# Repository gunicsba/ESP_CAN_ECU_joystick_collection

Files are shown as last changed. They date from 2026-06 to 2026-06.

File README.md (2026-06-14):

# Forwarder CAN Controller

ESP32-based CAN bus control system for a forwarder (logging machine) hydraulic valve block.
It replaces a failed factory controller with a robust, open-source solution using J1939-like addressing over a 250 kbps CAN bus.

## Overview

This project is split into three ECUs on one shared CAN network:

| ECU | Address | Role |
|-----|---|---|
| Motor Driver | `0x20` | Controls 8 solenoids via a PCA9685 PWM driver |
| Joystick 1 | `0x21` | Reads 3 potentiometers + 2 buttons and publishes data on CAN |
| Joystick 2 | `0x22` | Reads 3 potentiometers + 2 buttons and publishes data on CAN |

## Demo Video

See the joystick and CAN controller project in action:

- https://youtube.com/shorts/DkzHTf-jfCc?is=lRpg4t4KHVOdaWYg

## Why this project matters

This repository documents an open-source embedded controller for forestry machinery, specifically a forwarder crane control system with CAN bus joysticks, motor drivers, and hydraulic solenoid outputs. It is useful for anyone building or repairing custom CAN-based mobile machinery controls using ESP32 and PlatformIO.

## Hardware

### T-CAN485 (LilyGO) - Joystick ECU

- **MCU**: ESP32 (regular, not S3) with built-in TJA1050 CAN transceiver
- **CAN pins**: TX = GPIO27, RX = GPIO26
- **Transceiver control**: GPIO16 (`ME2107_EN`, must be HIGH), GPIO23 (`SPEED_MODE`, LOW = high-speed)
- **Joystick inputs**: 3 potentiometers on GPIO32, GPIO33, GPIO34 + 2 buttons on GPIO12 and GPIO5
- **Status LED**: WS2812B on GPIO18

### Motor Driver ECU

- **MCU**: LilyGO T-CAN board (ESP32 with built-in CAN transceiver)
- **Motor driver PCB**: PCA9685 I2C PWM controller with 8 MOSFET outputs

## Joystick Hardware

### Joystick used in this project

This project uses the following joystick model:

- AliExpress listing: https://www.aliexpress.com/item/1005001844154962.html

### 3rd axis wiring

For the 3rd axis on the joystick:

- **2x yellow wires**: button
- **White + red**: GND + power
- **Black**: signal

> The black wire is the signal wire, which is a bit unintuitive, but that is how this joystick is wired.

## 3D Printed Parts

### 3D printable joystick case

A 3D-printable case for the joystick is also included in this repository.

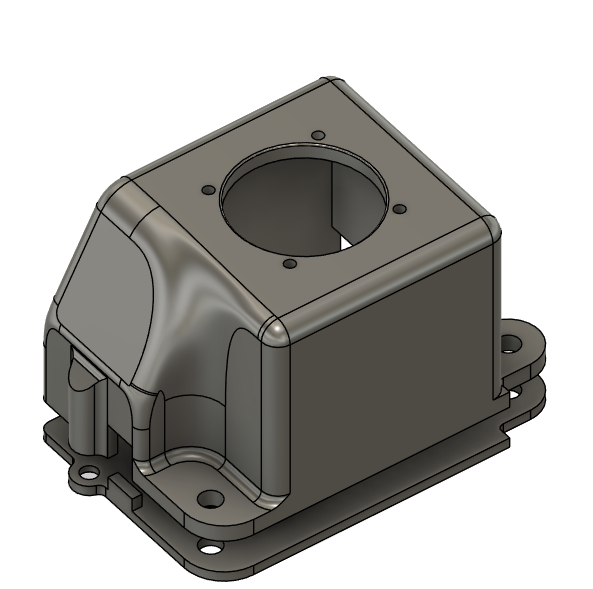
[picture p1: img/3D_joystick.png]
3D printable joystick case


## CAN Protocol

- **Bitrate**: 250 kbps
- **Frame format**: 29-bit extended IDs, J1939-style layout

### ID Structure

```
Bits 28-26: Priority (3 bits)
Bit 25:     Extended Data Page (0)
Bit 24:     Data Page (0)
Bits 23-16: PDU Format (PF)
Bits 15-8:  PDU Specific (PS) = Destination Address when PF < 240
Bits 7-0:   Source Address (SA)
```

### Joystick ECU Transmitted Messages (25Hz)

All messages are broadcast (PS = `0xFF`) with priority 6.

| PF | Name | Rate | Data Bytes | Description |
|----|---|---|---|---|
| `0x10` | `PF_JOYSTICK_POT1` | 25Hz | 2 | Potentiometer 1 value, little-endian (10-bit, 0-1023) |
| `0x11` | `PF_JOYSTICK_POT2` | 25Hz | 2 | Potentiometer 2 value, little-endian (10-bit, 0-1023) |
| `0x12` | `PF_JOYSTICK_POT3` | 25Hz | 2 | Potentiometer 3 value, little-endian (10-bit, 0-1023) |
| `0x13` | `PF_JOYSTICK_BUTTONS` | 25Hz | 1 | Button bitmask: bit0 = BTN1, bit1 = BTN2 |
| `0x30` | `PF_HEARTBEAT` | 1Hz | 8 | Status/heartbeat |

#### Potentiometer Data Format

```
Byte 0: value & 0xFF        (low byte)
Byte 1: (value >> 8) & 0xFF (high byte)
```

Example: value 512 → `data[0] = 0x00, data[1] = 0x02`

#### Button Data Format

```
Byte 0: bitmask
  bit 0: Button 1 (0x01) - active when pressed
  bit 1: Button 2 (0x02) - active when pressed
  bits 2-7: reserved (0)
```

Example: both buttons pressed → `data[0] = 0x03`

#### Heartbeat Data Format (PF `0x30`)

```
Byte 0: online flag (0x01 = address claimed, 0x00 = not claimed)
Byte 1: uptime seconds (low byte)
Byte 2: uptime seconds (high byte)
Byte 3: ECU joystick ID (1 or 2)
Byte 4: RX message count (low byte)
Byte 5: TX message count (low byte)
Byte 6-7: reserved (0)
```

### Network Management Messages

| PF | PS | Direction | Description | Payload |
|----|----|---|---|---|
| `0xEE` | `0xFF` | Broadcast | Address Claimed | 8-byte NAME (unique ECU identifier) |
| `0xEA` | `0xFF` | Broadcast | Request Address Claimed | - |

### Messages Received by Joystick ECU

| PF | PS | Source | Description | Payload |
|----|----|---|---|---|
| `0x20` | DA or `0xFF` | Any | Set LED Color | `R, G, B` (3 bytes) |
| `0x22` | DA or `0xFF` | Any | Identify (blink LED) | `duration` (1 byte, seconds) |

### Motor Driver Messages

| PF | PS | Direction | Description | Payload |
|----|----|---|---|---|
| `0x21` | DA | Any -> Motor | Solenoid Command | `duty0..duty7` (8 bytes, 0-255 each) |

## Pinout (T-CAN485 Joystick)

| Signal | GPIO | Notes |
|---|---|---|
| CAN TX | 27 | Built-in TJA1050 transceiver |
| CAN RX | 26 | Built-in TJA1050 transceiver |
| ME2107_EN | 16 | Transceiver power enable (HIGH) |
| SPEED_MODE | 23 | TJA1050 speed mode (LOW = high-speed) |
| WS2812 | 4 | Status LED |
| Pot 1 | 32 | Joystick X (analog input) |
| Pot 2 | 33 | Joystick Y (analog input) |
| Pot 3 | 34 | Joystick Z (analog input) |
| Button 1 | 12 | Active low, internal pullup |
| Button 2 | 5 | Active low, internal pullup |

## Joystick ECU LED Status Indicators

The WS2812B RGB LED on the joystick ECU provides visual status feedback:

| LED Pattern | Meaning | Condition |
|---|---|---|
| **Solid GREEN** (full brightness) | Normal operation | CAN bus online, motor ECU responding |
| **Solid RED** | Motor ECU offline | No CAN messages from motor ECU (`0x20`) for 1+ second |
| **Blinking RED** (500 ms) | CAN bus broken | No CAN messages from other devices for 2+ seconds |
| **Flashing WHITE** | Identify mode | `PF_IDENTIFY` message received, lasts 3 seconds |
| **Custom RGB** | Remote command | `PF_LED_COLOR` message overrides default color |

### Detection Logic

**Priority order** (highest to lowest):
1. Identify (white flash, 3 seconds)
2. CAN bus broken (blinking red) — message timeout + TWAI hardware check
3. Motor ECU offline (solid red) — message timeout
4. Custom LED color from `PF_LED_COLOR` command
5. Default green (`0, 255, 0`)

**CAN Bus Broken** is detected when any of:
- No CAN messages from **other devices** for 2+ seconds (own messages filtered to avoid loopback false negatives in `TWAI_MODE_NO_ACK`)
- `TWAI_STATE_STOPPED` — TWAI driver stopped
- `TWAI_STATE_BUS_OFF` — Bus-off due to errors
- `tx_error_counter >= 127` — High transmit error count

> **Note:** In `TWAI_MODE_NO_ACK`, the ESP32 may receive its own transmitted messages (loopback). The detection filters these out by checking `sa != g_can->getAddress()` so that a disconnected CAN node does not falsely appear healthy.

**Motor ECU Offline** is detected when:
- No CAN messages are received from source address `0x20` for more than 1 second
- It only triggers if the CAN bus is **not** broken (bus check has priority)

## Building & Flashing

Install [PlatformIO](https://platformio.org/) (VS Code extension or CLI).

```bash
# Build motor driver
pio run -e motor_driver

# Build joystick 1
pio run -e joystick1

# Build joystick 2
pio run -e joystick2

# Flash motor driver
pio run -e motor_driver --target upload

# Flash joystick 1
pio run -e joystick1 --target upload
```

### OTA Updates

OTA builds include a Wi-Fi access point and web upload interface.

```bash
# Build & upload joystick 1 with OTA support
pio run -e joystick1_ota --target upload
```

After booting:
1. Connect to the AP named `forwarder-joy1-21` (or `forwarder-joy2-22`)
2. Password: `12345678`
3. Open http://192.168.4.1
4. Upload a `.bin` firmware file

To produce a `.bin` for OTA:

```bash
pio run -e joystick1
# The .bin will be in .pio/build/joystick1/firmware.bin
```

## Screenshots

### Modules overview

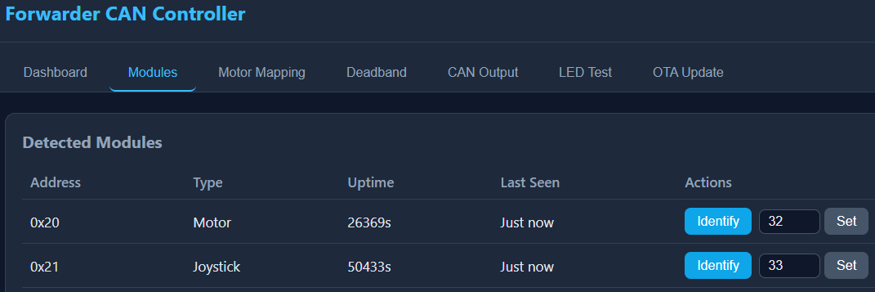
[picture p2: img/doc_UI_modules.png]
Modules overview


### Outputs view

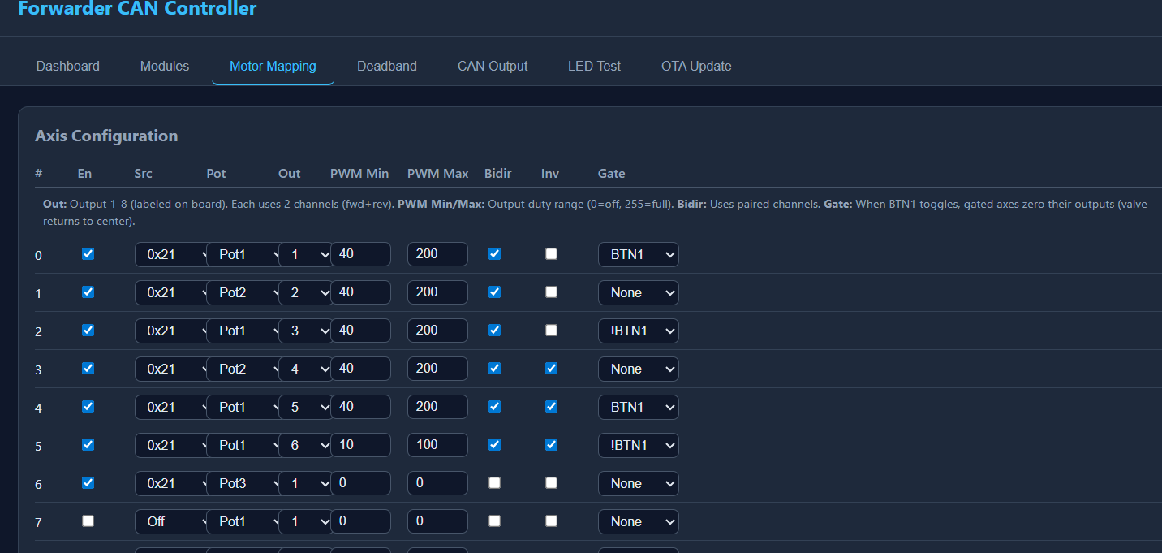
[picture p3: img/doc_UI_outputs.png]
Outputs view


### Deadband setup

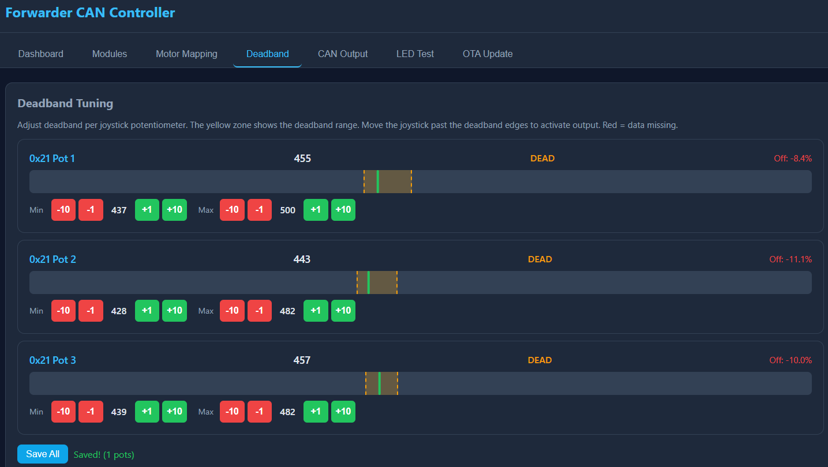
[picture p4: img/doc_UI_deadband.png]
Deadband setup


### Dashboard

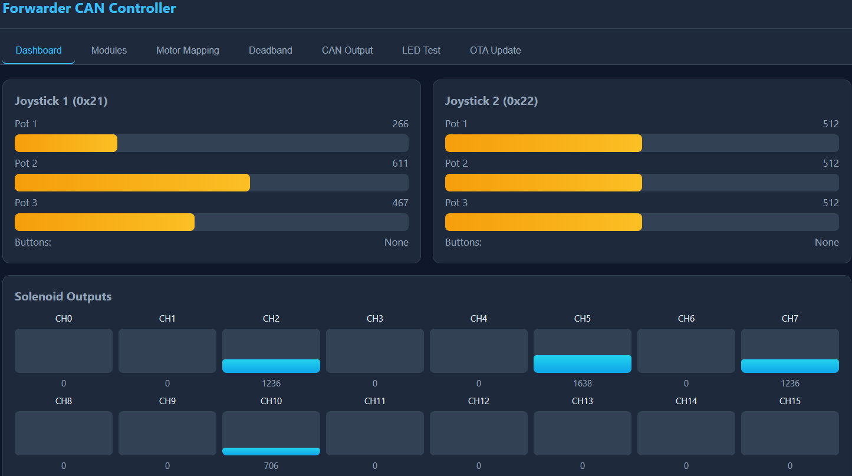
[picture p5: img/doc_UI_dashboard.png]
Dashboard


## Safety Features

- **Address claiming**: J1939-style startup arbitration ensures no address collisions
- **Solenoid timeout**: Motor driver shuts off all solenoids if no CAN command is received within 500 ms
- **Bus-off recovery**: Automatic TWAI recovery on CAN errors
- **Heartbeat**: All ECUs broadcast status every 1 second

## Project Structure

```
ESP_CAN_ECU_joystick_collection/
├── 3D/
├── img/
├── lib/
│   └── ForwarderCAN/
├── src/
│   ├── main.cpp
│   ├── ecu_motor_driver.cpp
│   ├── ecu_joystick.cpp
│   ├── ota_webserver.cpp
│   └── *.h
├── platformio.ini
├── build_flash.bat
└── README.md
```

## SEO Notes

Relevant search terms naturally covered in this README include: forwarder CAN controller, ESP32 CAN bus joystick, forestry crane controller, hydraulic solenoid driver, J1939-style CAN firmware, and open-source crane joystick electronics.

## License

MIT

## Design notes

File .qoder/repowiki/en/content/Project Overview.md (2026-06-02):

# Project Overview

<cite>
**Referenced Files in This Document**
- [README.md](file://README.md)
- [main.cpp](file://src/main.cpp)
- [platformio.ini](file://platformio.ini)
- [ForwarderCAN.h](file://lib/ForwarderCAN/ForwarderCAN.h)
- [ForwarderCAN.cpp](file://lib/ForwarderCAN/ForwarderCAN.cpp)
- [ecu_motor_driver.cpp](file://src/ecu_motor_driver.cpp)
- [ecu_motor_driver.h](file://src/ecu_motor_driver.h)
- [ecu_joystick.cpp](file://src/ecu_joystick.cpp)
- [ecu_joystick.h](file://src/ecu_joystick.h)
- [can_output.h](file://src/can_output.h)
- [can_output.cpp](file://src/can_output.cpp)
- [web_state.h](file://src/web_state.h)
- [web_state.cpp](file://src/web_state.cpp)
</cite>

## Table of Contents
1. [Introduction](#introduction)
2. [Project Structure](#project-structure)
3. [Core Components](#core-components)
4. [Architecture Overview](#architecture-overview)
5. [Detailed Component Analysis](#detailed-component-analysis)
6. [Dependency Analysis](#dependency-analysis)
7. [Performance Considerations](#performance-considerations)
8. [Troubleshooting Guide](#troubleshooting-guide)
9. [Conclusion](#conclusion)

## Introduction
ForwarderKE is an open-source, ESP32-S3-based control system designed to replace factory controllers in agricultural forwarder (logging machine) hydraulic valve blocks. It implements a J1939-like CAN protocol over a 250 kbps bus to coordinate a three-ECU architecture: a Motor Driver ECU controlling solenoids, and two Joystick ECUs for operator input. The system emphasizes robustness, safety, and transparency through open-source firmware and hardware, enabling operators and integrators to customize and maintain their equipment independently.

Target applications include:
- Replacing proprietary controllers in forwarders and similar agricultural machines
- Providing a transparent, modifiable control stack for research, education, and rapid prototyping
- Enabling field diagnostics, remote updates (OTA), and flexible I/O mapping

Key benefits of the open-source approach:
- Full visibility into control logic and communication
- Community-driven improvements and bug fixes
- Reduced vendor lock-in and long-term maintenance costs
- Support for custom I/O mapping and output rules

## Project Structure
The project is organized around a small set of libraries and ECUs:
- A shared CAN/J1939-like library encapsulates protocol parsing, address claiming, and TWAI driver integration
- Two ECU implementations: one for joysticks (inputs) and one for motor control (outputs)
- A small CAN output rule engine for mapping CAN events to GPIO pins
- A web state module exposing runtime state for optional OTA web UI
- Build environments managed via PlatformIO with separate targets for each ECU and OTA variants

```mermaid
graph TB
subgraph "Build Environments"
MD["motor_driver<br/>address 0x20"]
J1["joystick1<br/>address 0x21"]
J2["joystick2<br/>address 0x22"]
OTA_MD["motor_driver_ota"]
OTA_J1["joystick1_ota"]
OTA_J2["joystick2_ota"]
end
subgraph "ECUs"
ECUMD["Motor Driver ECU"]
ECUJ1["Joystick 1 ECU"]
ECUJ2["Joystick 2 ECU"]
end
subgraph "Shared Library"
LIB["ForwarderCAN<br/>J1939-like protocol<br/>address claiming"]
end
subgraph "Outputs"
OUT["GPIO + PCA9685 PWM<br/>Solenoids"]
LED["Status LED"]
end
MD --> ECUMD
J1 --> ECUJ1
J2 --> ECUJ2
OTA_MD --> ECUMD
OTA_J1 --> ECUJ1
OTA_J2 --> ECUJ2
ECUMD --> LIB
ECUJ1 --> LIB
ECUJ2 --> LIB
ECUMD --> OUT
ECUMD --> LED
ECUJ1 --> LED
ECUJ2 --> LED
```

**Diagram sources**
- [platformio.ini:17-79](file://platformio.ini#L17-L79)
- [ForwarderCAN.h:66-119](file://lib/ForwarderCAN/ForwarderCAN.h#L66-L119)
- [ecu_motor_driver.cpp:290-323](file://src/ecu_motor_driver.cpp#L290-L323)
- [ecu_joystick.cpp:159-191](file://src/ecu_joystick.cpp#L159-L191)

**Section sources**
- [README.md:112-126](file://README.md#L112-L126)
- [platformio.ini:1-80](file://platformio.ini#L1-L80)

## Core Components
- ForwarderCAN library: Implements J1939-like 29-bit ID layout, address claiming, and TWAI driver integration. Provides APIs for sending/receiving messages, broadcasting, and monitoring statistics.
- Motor Driver ECU: Reads joystick data, maps axes to solenoid outputs via PCA9685 PWM, manages LEDs, and supports configuration and heartbeat messages.
- Joystick ECUs: Read analog pots and buttons, publish joystick data and button states, manage LEDs, and handle address assignment requests.
- CAN Output Rules: Optional mapping of CAN frames to GPIO pins for toggling or momentary pulses.

**Section sources**
- [ForwarderCAN.h:66-119](file://lib/ForwarderCAN/ForwarderCAN.h#L66-L119)
- [ecu_motor_driver.cpp:290-350](file://src/ecu_motor_driver.cpp#L290-L350)
- [ecu_joystick.cpp:159-236](file://src/ecu_joystick.cpp#L159-L236)
- [can_output.h:7-11](file://src/can_output.h#L7-L11)

## Architecture Overview
The system operates on a 250 kbps CAN bus with J1939-like addressing. Three ECUs coexist:
- Motor Driver ECU at address 0x20 controls 8 solenoids (16 with dual PCA9685), receives joystick data, and broadcasts heartbeat/status
- Joystick 1 ECU at address 0x21 reads 3 pots + 2 buttons and publishes joystick frames
- Joystick 2 ECU at address 0x22 mirrors joystick 1’s role

```mermaid
graph TB
Bus["250 kbps CAN Bus"]
MD["Motor Driver ECU<br/>Address 0x20"]
J1["Joystick 1 ECU<br/>Address 0x21"]
J2["Joystick 2 ECU<br/>Address 0x22"]
PCA["PCA9685 PWM Controller(s)"]
LEDM["Status LED (MD)"]
LEDJ["Status LED (J1/J2)"]
Bus --> MD
Bus --> J1
Bus --> J2
MD --> PCA
MD --> LEDM
J1 --> LEDJ
J2 --> LEDJ
```

**Diagram sources**
- [README.md:8-14](file://README.md#L8-L14)
- [platformio.ini:17-61](file://platformio.ini#L17-L61)
- [ecu_motor_driver.cpp:39-41](file://src/ecu_motor_driver.cpp#L39-L41)
- [ecu_joystick.cpp:39](file://src/ecu_joystick.cpp#L39)

## Detailed Component Analysis

### ForwarderCAN Library
The library encapsulates:
- J1939-like ID packing/unpacking macros and constants
- Address claiming state machine with arbitration and retries
- TWAI driver initialization, bus-off recovery, and message send/receive
- Statistics counters for TX/RX/error counts

```mermaid
classDiagram
class ForwarderCAN {
-uint8_t _preferredAddress
-uint8_t _currentAddress
-uint8_t _name[8]
-AddrClaimState _state
-uint32_t _claimTimer
-uint32_t _claimAttempts
+ForwarderCAN(preferredAddress, name)
+begin(txPin, rxPin, bitrate) bool
+loop() void
+send(pf, ps, data, len, priority) bool
+sendBroadcast(pf, data, len, priority) bool
+receive(msg, timeoutMs) bool
+hasMessage() bool
+isOnline() bool
+getAddress() uint8_t
+getState() AddrClaimState
+getTxCount() uint32_t
+getRxCount() uint32_t
+getErrorCount() uint32_t
-sendAddressClaimed() void
-processNetworkManagement(msg) void
-tryClaimAddress() void
}
```

**Diagram sources**
- [ForwarderCAN.h:66-119](file://lib/ForwarderCAN/ForwarderCAN.h#L66-L119)
- [ForwarderCAN.cpp:3-119](file://lib/ForwarderCAN/ForwarderCAN.cpp#L3-L119)

**Section sources**
- [ForwarderCAN.h:9-57](file://lib/ForwarderCAN/ForwarderCAN.h#L9-L57)
- [ForwarderCAN.cpp:13-52](file://lib/ForwarderCAN/ForwarderCAN.cpp#L13-L52)
- [ForwarderCAN.cpp:54-119](file://lib/ForwarderCAN/ForwarderCAN.cpp#L54-L119)

### Motor Driver ECU
Responsibilities:
- Initialize PCA9685 PWM controllers (detect dual controller), set frequency, and map axis values to PWM
- Receive joystick pots and buttons, compute solenoid outputs per axis configuration, and apply deadband/bidirectional mapping
- Handle LED color, identify, and heartbeat messages; enforce safety timeout to turn off solenoids after inactivity
- Manage CAN output rules for GPIO mapping

```mermaid
flowchart TD
Start(["ECU Loop"]) --> CANRecv["Receive CAN Frames"]
CANRecv --> Dispatch{"PF Type"}
Dispatch --> |Joystick Pots| UpdatePots["Store Pot Values<br/>and Update Time"]
Dispatch --> |Solenoid Command| ApplyCmd["Scale 0-255 to 12-bit<br/>Apply PWM"]
Dispatch --> |LED Color| SetLED["Update LED RGB"]
Dispatch --> |Identify| Blink["Blink LED for 3s"]
Dispatch --> |Set Address| SaveAddr["Persist Forced Address<br/>Reboot"]
Dispatch --> |Config Axis| SaveCfg["Save Axis Config"]
Dispatch --> |Request Config| ReplyCfg["Reply All Axis Configs"]
Dispatch --> |Heartbeat| Ignore["Ignore (handled by sender)"]
UpdatePots --> Axes["Map Axes to Outputs"]
ApplyCmd --> Axes
Axes --> PWM["Write PCA9685 Channels"]
PWM --> BlinkFast["Fast Blink"]
BlinkFast --> TimeoutCheck{"Safety Timeout > 500ms?"}
TimeoutCheck --> |Yes| AllOff["Turn Off All Solenoids"]
TimeoutCheck --> |No| NextHB["Next Heartbeat"]
AllOff --> NextHB
NextHB --> Heartbeat["Broadcast Heartbeat"]
Heartbeat --> LEDUpdate["Update LED Pattern"]
LEDUpdate --> End(["Loop End"])
```

**Diagram sources**
- [ecu_motor_driver.cpp:184-275](file://src/ecu_motor_driver.cpp#L184-L275)
- [ecu_motor_driver.cpp:137-151](file://src/ecu_motor_driver.cpp#L137-L151)
- [ecu_motor_driver.cpp:330-335](file://src/ecu_motor_driver.cpp#L330-L335)
- [ecu_motor_driver.cpp:277-288](file://src/ecu_motor_driver.cpp#L277-L288)

**Section sources**
- [ecu_motor_driver.cpp:290-350](file://src/ecu_motor_driver.cpp#L290-L350)
- [ecu_motor_driver.cpp:69-99](file://src/ecu_motor_driver.cpp#L69-L99)
- [ecu_motor_driver.cpp:101-135](file://src/ecu_motor_driver.cpp#L101-L135)
- [ecu_motor_driver.cpp:184-275](file://src/ecu_motor_driver.cpp#L184-L275)

### Joystick ECUs
Responsibilities:
- Read 3 pots and 2 buttons, publish pot and button frames at ~100 ms intervals or on change
- Respond to LED color and identify commands; persist forced address on request
- Broadcast heartbeat with online status and counters

```mermaid
sequenceDiagram
participant J as "Joystick ECU"
participant CAN as "ForwarderCAN"
participant MD as "Motor Driver ECU"
J->>J : "Read pots/buttons"
J->>CAN : "sendBroadcast(PF_JOYSTICK_POT1/2,<value>)"
J->>CAN : "sendBroadcast(PF_JOYSTICK_BUTTONS,<mask>)"
J->>CAN : "sendBroadcast(PF_HEARTBEAT)"
CAN-->>MD : "Broadcast Joystick Frames"
MD->>MD : "Update solenoid mapping"
MD->>CAN : "sendBroadcast(PF_HEARTBEAT)"
```

**Diagram sources**
- [ecu_joystick.cpp:194-236](file://src/ecu_joystick.cpp#L194-L236)
- [ecu_motor_driver.cpp:184-204](file://src/ecu_motor_driver.cpp#L184-L204)

**Section sources**
- [ecu_joystick.cpp:159-191](file://src/ecu_joystick.cpp#L159-L191)
- [ecu_joystick.cpp:194-236](file://src/ecu_joystick.cpp#L194-L236)

### CAN Output Rules Engine
Maps incoming CAN frames to GPIO pins:
- Toggle mode flips output state on match
- Momentary mode sets output HIGH for a configured duration then LOW

```mermaid
flowchart TD
RStart(["CAN Frame Received"]) --> Match["Match Rules by PF/SA"]
Match --> Mode{"Mode: Toggle or Momentary"}
Mode --> |Toggle| Flip["Flip Output State"]
Mode --> |Momentary| Pulse["Set Output HIGH<br/>Schedule Timer"]
Pulse --> Timer["On Timer Expire<br/>Set Output LOW"]
Flip --> REnd(["Done"])
Timer --> REnd
```

**Diagram sources**
- [can_output.cpp:29-61](file://src/can_output.cpp#L29-L61)

**Section sources**
- [can_output.h:7-11](file://src/can_output.h#L7-L11)
- [can_output.cpp:7-19](file://src/can_output.cpp#L7-L19)
- [can_output.cpp:29-61](file://src/can_output.cpp#L29-L61)

## Dependency Analysis
- Build-time selection: The main entry chooses the ECU implementation via build flags, ensuring only one ECU is compiled per environment.
- Runtime dependencies:
  - ECUs depend on ForwarderCAN for protocol and addressing
  - Motor Driver depends on PCA9685 drivers and NeoPixel for LEDs
  - Joystick ECUs depend on NeoPixel for LEDs and optional CAN SE pin for transceiver enable
  - Optional OTA web server is enabled per environment

```mermaid
graph LR
MAIN["main.cpp"] --> |includes| MDH["ecu_motor_driver.h"]
MAIN --> |includes| JH["ecu_joystick.h"]
MDH --> MCPP["ecu_motor_driver.cpp"]
JH --> JCPP["ecu_joystick.cpp"]
MCPP --> FC_H["ForwarderCAN.h"]
JCPP --> FC_H
MCPP --> PCA["Adafruit_PWMServoDriver"]
MCPP --> NP["NeoPixelBus"]
JCPP --> NP
FC_H --> FCPP["ForwarderCAN.cpp"]
```

**Diagram sources**
- [main.cpp:11-17](file://src/main.cpp#L11-L17)
- [ecu_motor_driver.cpp:1-12](file://src/ecu_motor_driver.cpp#L1-L12)
- [ecu_joystick.cpp:1-9](file://src/ecu_joystick.cpp#L1-L9)
- [ForwarderCAN.h:3-4](file://lib/ForwarderCAN/ForwarderCAN.h#L3-L4)
- [ForwarderCAN.cpp:1](file://lib/ForwarderCAN/ForwarderCAN.cpp#L1)

**Section sources**
- [main.cpp:11-17](file://src/main.cpp#L11-L17)
- [platformio.ini:17-79](file://platformio.ini#L17-L79)

## Performance Considerations
- TWAI driver tuning: The library configures TX/RX queues and timing based on bitrate, ensuring reliable frame reception under load.
- Address claiming: The state machine retries up to a limit and falls back to an alternate address derived from the device name, minimizing startup stalls.
- Safety timeout: The motor driver disables solenoids after 500 ms without CAN commands, preventing unintended actuation.
- Heartbeat cadence: All ECUs broadcast status every 1 second, balancing diagnostics visibility with bus utilization.

[No sources needed since this section provides general guidance]

## Troubleshooting Guide
Common issues and remedies:
- CAN initialization failure: The motor driver flashes a red LED pattern and loops when TWAI fails to start; verify wiring and pin assignments.
- Address collision: If another ECU occupies the preferred address, the claiming state machine retries and may switch to an alternate address; check logs for claim attempts and verify unique addresses.
- Bus-off state: The library automatically initiates recovery upon detecting bus-off; inspect wiring and power integrity if recovery loops occur frequently.
- OTA upload problems: Ensure the correct environment is selected and the device connects to the AP; confirm the generated firmware binary location.

**Section sources**
- [ecu_motor_driver.cpp:305-316](file://src/ecu_motor_driver.cpp#L305-L316)
- [ForwarderCAN.cpp:42-47](file://lib/ForwarderCAN/ForwarderCAN.cpp#L42-L47)
- [ForwarderCAN.cpp:98-109](file://lib/ForwarderCAN/ForwarderCAN.cpp#L98-L109)
- [README.md:84-103](file://README.md#L84-L103)

## Conclusion
ForwarderKE delivers a robust, open-source replacement for factory controllers in agricultural forwarders. Its J1939-like protocol, three-ECU architecture, and safety-focused design enable reliable operation in demanding environments. The modular library and clear separation of concerns make it straightforward to extend, debug, and deploy across diverse applications.

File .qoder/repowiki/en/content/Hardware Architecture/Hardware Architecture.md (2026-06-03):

# Hardware Architecture

<cite>
**Referenced Files in This Document**
- [README.md](file://README.md)
- [platformio.ini](file://platformio.ini)
- [src/main.cpp](file://src/main.cpp)
- [src/ecu_motor_driver.cpp](file://src/ecu_motor_driver.cpp)
- [src/ecu_motor_driver.h](file://src/ecu_motor_driver.h)
- [src/ecu_joystick.cpp](file://src/ecu_joystick.cpp)
- [src/ecu_joystick.h](file://src/ecu_joystick.h)
- [src/can_output.cpp](file://src/can_output.cpp)
- [src/can_output.h](file://src/can_output.h)
- [src/web_state.h](file://src/web_state.h)
- [src/web_state.cpp](file://src/web_state.cpp)
- [lib/ForwarderCAN/ForwarderCAN.h](file://lib/ForwarderCAN/ForwarderCAN.h)
</cite>

## Update Summary
**Changes Made**
- Updated MCU specification from ESP32-S3 to standard ESP32 microcontrollers
- Replaced generic CAN_SE_PIN naming with new CAN_ME2107_EN_PIN and CAN_SPEED_MODE_PIN conventions
- Updated pin assignments for T-CAN485 board with correct GPIO mappings
- Revised CAN transceiver control methodology for TJA1050-based boards

## Table of Contents
1. [Introduction](#introduction)
2. [Project Structure](#project-structure)
3. [Core Components](#core-components)
4. [Architecture Overview](#architecture-overview)
5. [Detailed Component Analysis](#detailed-component-analysis)
6. [Dependency Analysis](#dependency-analysis)
7. [Performance Considerations](#performance-considerations)
8. [Troubleshooting Guide](#troubleshooting-guide)
9. [Conclusion](#conclusion)
10. [Appendices](#appendices)

## Introduction
This document describes the hardware architecture of ForwarderKE, focusing on the physical system design and component interconnections. It covers the MCU board, CAN transceiver, peripheral pin assignments, PCA9685 PWM controller for solenoid control, joystick input circuitry, CAN bus topology, and safety considerations for high-current solenoid loads.

## Project Structure
The hardware design is implemented across a small set of source files and build environments. The entry point selects the ECU type at compile time, and each ECU type initializes its own peripherals and CAN stack.

```mermaid
graph TB
A["src/main.cpp<br/>Entry point"] --> B["src/ecu_motor_driver.cpp<br/>Motor driver ECU"]
A --> C["src/ecu_joystick.cpp<br/>Joystick ECU"]
B --> D["src/can_output.cpp<br/>CAN output rules"]
B --> E["src/web_state.h<br/>Shared state"]
C --> E
E --> F["src/web_state.cpp<br/>Default definitions"]
```

**Diagram sources**
- [src/main.cpp:19-31](file://src/main.cpp#L19-L31)
- [src/ecu_motor_driver.cpp:290-323](file://src/ecu_motor_driver.cpp#L290-L323)
- [src/ecu_joystick.cpp:159-192](file://src/ecu_joystick.cpp#L159-L192)
- [src/can_output.cpp:7-19](file://src/can_output.cpp#L7-L19)
- [src/web_state.h:10-23](file://src/web_state.h#L10-L23)
- [src/web_state.cpp:3-19](file://src/web_state.cpp#L3-L19)

**Section sources**
- [src/main.cpp:19-31](file://src/main.cpp#L19-L31)
- [README.md:112-126](file://README.md#L112-L126)

## Core Components
- MCU and Board: Standard ESP32-based LilyGO T-CAN board with integrated TJA1050 CAN transceiver.
- CAN Bus: 250 kbps, 29-bit extended IDs using J1939-like addressing.
- Motor Driver ECU: Controls up to 16 solenoids via PCA9685 I2C PWM drivers.
- Joystick ECUs: Read 3 potentiometers and 2 buttons, publish joystick data on CAN.
- Status LED: Single WS2812 RGB LED for system status indication.
- Optional OTA: Wi-Fi AP and web server for firmware updates.

**Section sources**
- [README.md:16-21](file://README.md#L16-L21)
- [README.md:22-46](file://README.md#L22-L46)
- [platformio.ini:17-30](file://platformio.ini#L17-L30)
- [platformio.ini:31-62](file://platformio.ini#L31-L62)

## Architecture Overview
The system consists of three ECUs on a single 250 kbps CAN bus:
- Motor Driver ECU (address 0x20): Receives solenoid commands and controls PCA9685 channels.
- Joystick ECU 1 (address 0x21): Publishes joystick potentiometer values and button states.
- Joystick ECU 2 (address 0x22): Identical to ECU 1, compiled for a different unit.

```mermaid
graph TB
subgraph "CAN Bus (250 kbps)"
MD["Motor Driver ECU 0x20"]
JS1["Joystick ECU 1 0x21"]
JS2["Joystick ECU 2 0x22"]
end
JS1 --> |Joystick Pots/Buttons| CAN["CAN Bus"]
JS2 --> |Joystick Pots/Buttons| CAN
MD --> |Solenoid Commands| CAN
MD --> |PCA9685 PWM| SOLENOIDS["Solenoids"]
LED_MD["WS2812 LED (Motor Driver)"] --- MD
LED_JS["WS2812 LED (Joysticks)"] --- JS1
LED_JS2["WS2812 LED (Joystick 2)"] --- JS2
```

**Diagram sources**
- [README.md:8-14](file://README.md#L8-L14)
- [README.md:31-41](file://README.md#L31-L41)
- [platformio.ini:17-30](file://platformio.ini#L17-L30)
- [platformio.ini:31-62](file://platformio.ini#L31-L62)

## Detailed Component Analysis

### Standard ESP32 LilyGO T-CAN Board and TJA1050 CAN Transceiver
- Built-in TJA1050 CAN transceiver pins are mapped to MCU GPIOs.
- Motor Driver ECU uses GPIO 5 (TX) and GPIO 4 (RX) for CAN communication.
- Joystick ECUs define separate CAN pins and use dedicated transceiver control pins:
  - CAN_ME2107_EN_PIN (GPIO 16): Transceiver power enable (must be HIGH)
  - CAN_SPEED_MODE_PIN (GPIO 23): Speed mode control (LOW = high-speed, up to 1Mbps)

```mermaid
sequenceDiagram
participant MCU as "ESP32 MCU"
participant TRX as "TJA1050 CAN Transceiver"
participant BUS as "CAN Bus"
MCU->>TRX : "Configure TX/RX pins"
MCU->>TRX : "Enable transceiver (ME2107_EN=HIGH)"
MCU->>TRX : "Set speed mode (SPEED_MODE=LOW)"
TRX->>BUS : "Transmit frames"
BUS-->>TRX : "Receive frames"
TRX-->>MCU : "Deliver frames"
```

**Diagram sources**
- [README.md:48-62](file://README.md#L48-L62)
- [platformio.ini:23-24](file://platformio.ini#L23-L24)
- [platformio.ini:38-40](file://platformio.ini#L38-L40)
- [platformio.ini:54-56](file://platformio.ini#L54-L56)
- [src/ecu_joystick.cpp:190-197](file://src/ecu_joystick.cpp#L190-L197)

**Section sources**
- [README.md:18](file://README.md#L18)
- [README.md:48-62](file://README.md#L48-L62)
- [platformio.ini:17-30](file://platformio.ini#L17-L30)
- [platformio.ini:31-62](file://platformio.ini#L31-L62)
- [src/ecu_joystick.cpp:190-197](file://src/ecu_joystick.cpp#L190-L197)

### PCA9685 PWM Controller for Solenoid Control
- I2C addresses: PCA9685_I2C_ADDR1 (default 0x40), PCA9685_I2C_ADDR2 (default 0x41).
- Two PCA9685 chips can be present for up to 16 channels (8 per chip).
- PWM frequency configured to 200 Hz; 12-bit precision internally mapped from 8-bit duty cycle.
- Motor driver reads joystick pot values and maps them to solenoid PWM outputs with deadband and direction logic.

```mermaid
flowchart TD
Start(["Joystick Pot Value"]) --> CheckEnabled{"Axis Enabled?"}
CheckEnabled --> |No| Off["Set PWM 0"]
CheckEnabled --> |Yes| Dir{"Bidirectional?"}
Dir --> |Yes| DeadRev{"Below Deadband Min?"}
DeadRev --> |Yes| MapRev["Map Reverse Range to PWM"]
DeadRev --> |No| DeadFwd{"Above Deadband Max?"}
DeadFwd --> |Yes| MapFwd["Map Forward Range to PWM"]
DeadFwd --> |No| DeadZone["Zero Output"]
Dir --> |No| MapFwd2["Map Forward Range to PWM"]
MapRev --> Out["Apply PCA9685 Channel PWM"]
MapFwd --> Out
DeadZone --> Out
MapFwd2 --> Out
Off --> End(["Done"])
Out --> End
```

**Diagram sources**
- [src/ecu_motor_driver.cpp:101-135](file://src/ecu_motor_driver.cpp#L101-L135)
- [src/ecu_motor_driver.cpp:69-76](file://src/ecu_motor_driver.cpp#L69-L76)
- [platformio.ini:26-28](file://platformio.ini#L26-L28)

**Section sources**
- [README.md:19](file://README.md#L19)
- [platformio.ini:26-28](file://platformio.ini#L26-L28)
- [src/ecu_motor_driver.cpp:85-99](file://src/ecu_motor_driver.cpp#L85-L99)
- [src/ecu_motor_driver.cpp:101-135](file://src/ecu_motor_driver.cpp#L101-L135)
- [src/ecu_motor_driver.cpp:69-76](file://src/ecu_motor_driver.cpp#L69-L76)

### Joystick Input Circuitry (3 Potentiometers + 2 Buttons)
- Potentiometer inputs: ADC resolution 10-bit with 11 dB attenuation.
- Buttons: Active-low with internal pull-up resistors.
- LED status: WS2812 RGB LED indicates connection and identification states.

```mermaid
flowchart TD
A["Read POT1/POT2 (ADC 10-bit)"] --> B["Read BTN1/BTN2 (INPUT_PULLUP)"]
B --> C{"Any Change?"}
C --> |Yes| D["Send CAN Joystick Messages"]
C --> |No| E{"100ms Timer?"}
E --> |Yes| F["Send CAN (Periodic)"]
E --> |No| G["Update LED"]
D --> G
F --> G
```

**Diagram sources**
- [src/ecu_joystick.cpp:63-68](file://src/ecu_joystick.cpp#L63-L68)
- [src/ecu_joystick.cpp:194-236](file://src/ecu_joystick.cpp#L194-L236)
- [src/ecu_joystick.cpp:163-166](file://src/ecu_joystick.cpp#L163-L166)

**Section sources**
- [README.md:57-61](file://README.md#L57-L61)
- [src/ecu_joystick.cpp:63-68](file://src/ecu_joystick.cpp#L63-L68)
- [src/ecu_joystick.cpp:163-166](file://src/ecu_joystick.cpp#L163-L166)

### CAN Bus Topology, Termination, and Signal Integrity
- Bitrate: 250 kbps.
- Extended ID format: Priority(3) | DP(1) | PF(8) | PS/DA(8) | SA(8).
- Addressing: ECU addresses 0x20 (Motor Driver), 0x21 (Joystick 1), 0x22 (Joystick 2).
- Termination: Recommended 120 Ω termination resistors at both ends of the bus.
- Signal integrity: Keep CAN pair traces short and equal length; avoid high-frequency noise near analog inputs.

```mermaid
sequenceDiagram
participant JS as "Joystick ECU"
participant MD as "Motor Driver ECU"
participant BUS as "CAN Bus"
JS->>BUS : "Joystick Pot1/Pot2/Buttons"
BUS-->>MD : "Frame with PF=0x10..0x13"
MD->>MD : "Store joystick values"
MD->>BUS : "Solenoid Command (PF=0x21)"
BUS-->>JS : "Heartbeat/Status"
```

**Diagram sources**
- [README.md:24-41](file://README.md#L24-L41)
- [README.md:8-14](file://README.md#L8-L14)

**Section sources**
- [README.md:22-27](file://README.md#L22-L27)
- [README.md:29-41](file://README.md#L29-L41)
- [README.md:8-14](file://README.md#L8-L14)

### Status LED Indication
- WS2812 LED is used for system status:
  - Solid green: Ready.
  - Blinking amber: Offline or warning.
  - Fast blinking: Activity from joystick input.
  - White flash: Identify command response.
  - Error pattern: Rapid off/on during initialization failure.

```mermaid
stateDiagram-v2
[*] --> Ready
Ready --> Online : "CAN OK"
Online --> Offline : "CAN Lost"
Offline --> Warning : "Blink Cycle"
Warning --> Online : "Recovered"
Online --> Activity : "Joystick Update"
Activity --> Online : "Timeout"
Ready --> Error : "Init Fail"
Error --> Error : "Blink Pattern"
```

**Diagram sources**
- [src/ecu_motor_driver.cpp:153-182](file://src/ecu_motor_driver.cpp#L153-L182)
- [src/ecu_joystick.cpp:70-97](file://src/ecu_joystick.cpp#L70-L97)

**Section sources**
- [README.md:54](file://README.md#L54)
- [src/ecu_motor_driver.cpp:153-182](file://src/ecu_motor_driver.cpp#L153-L182)
- [src/ecu_joystick.cpp:70-97](file://src/ecu_joystick.cpp#L70-L97)

### CAN Output Rules (External GPIO Outputs)
- Optional feature allowing mapping of incoming CAN messages to external GPIO pins.
- Supports toggle and momentary modes with configurable pulse duration.
- Useful for auxiliary outputs beyond solenoids.

```mermaid
flowchart TD
Start(["CAN Frame Received"]) --> Match{"Match PF/SA?"}
Match --> |No| End(["Ignore"])
Match --> |Yes| Mode{"Mode: Toggle or Momentary"}
Mode --> |Toggle| Toggle["Flip Output State"]
Mode --> |Momentary| Pulse["Set HIGH, Start Timer"]
Pulse --> Timer{"Timer Expired?"}
Timer --> |Yes| Clear["Set LOW"]
Timer --> |No| Wait["Wait"]
Clear --> End
Toggle --> End
Wait --> End
```

**Diagram sources**
- [src/can_output.cpp:29-49](file://src/can_output.cpp#L29-L49)
- [src/can_output.cpp:51-61](file://src/can_output.cpp#L51-L61)

**Section sources**
- [src/can_output.cpp:7-19](file://src/can_output.cpp#L7-L19)
- [src/can_output.cpp:29-49](file://src/can_output.cpp#L29-L49)
- [src/can_output.cpp:51-61](file://src/can_output.cpp#L51-L61)

## Dependency Analysis
- Build-time selection determines which ECU logic is linked:
  - ECU_TYPE_MOTOR_DRIVER: Includes PCA9685, motor mapping, heartbeat, and CAN output rules.
  - ECU_TYPE_JOYSTICK: Includes ADC/button reading, LED control, and periodic CAN publishing.
- Shared CAN/J1939 protocol and configuration are provided by the ForwarderCAN and ForwarderConfig libraries referenced in the build.

```mermaid
graph LR
PIO["platformio.ini<br/>Build Flags"] --> MAIN["src/main.cpp"]
MAIN --> MD["ecu_motor_driver.cpp"]
MAIN --> JS["ecu_joystick.cpp"]
MD --> CANOUT["can_output.cpp"]
MD --> CFG["ForwarderConfig"]
JS --> CFG
MD --> CANLIB["ForwarderCAN"]
JS --> CANLIB
```

**Diagram sources**
- [platformio.ini:17-30](file://platformio.ini#L17-L30)
- [platformio.ini:31-62](file://platformio.ini#L31-L62)
- [src/main.cpp:11-17](file://src/main.cpp#L11-L17)
- [src/ecu_motor_driver.cpp:8-12](file://src/ecu_motor_driver.cpp#L8-L12)
- [src/ecu_joystick.cpp:5-9](file://src/ecu_joystick.cpp#L5-L9)

**Section sources**
- [src/main.cpp:11-17](file://src/main.cpp#L11-L17)
- [platformio.ini:17-30](file://platformio.ini#L17-L30)
- [platformio.ini:31-62](file://platformio.ini#L31-L62)

## Performance Considerations
- CAN bitrate: 250 kbps balances responsiveness and reliability for this application.
- Joystick update cadence: Values sent when changed beyond a threshold or periodically every 100 ms.
- Motor driver safety: All solenoids are turned off after 500 ms without a valid command.
- LED refresh: Throttled to ~20 FPS to reduce CPU load.
- I2C bus speed: PCA9685 initialized at 200 Hz PWM; keep I2C polling minimal.

## Troubleshooting Guide
- CAN initialization failure: Motor driver and joystick ECUs enter a blinking red error pattern until resolved.
- No joystick data reaching solenoids: Verify joystick address and that Motor Driver ECU is online; check heartbeat messages.
- PCA9685 not responding: Confirm I2C pins and addresses; the driver auto-detects a second PCA9685 at 0x41.
- Buttons not registering: Ensure pull-up configuration and active-low wiring; debounce is handled in firmware logic.
- OTA upload issues: Confirm Wi-Fi AP SSID/password and web UI availability.
- Transceiver not enabling: Verify CAN_ME2107_EN_PIN is set HIGH and CAN_SPEED_MODE_PIN is set LOW for high-speed operation.

**Section sources**
- [src/ecu_motor_driver.cpp:305-316](file://src/ecu_motor_driver.cpp#L305-L316)
- [src/ecu_joystick.cpp:175-185](file://src/ecu_joystick.cpp#L175-L185)
- [README.md:105-111](file://README.md#L105-L111)

## Conclusion
ForwarderKE's hardware architecture centers on a standard ESP32-based board with integrated TJA1050 CAN transceiver, a robust J1939-like CAN protocol, and flexible ECU roles. The Motor Driver ECU controls up to 16 solenoids via PCA9685, while Joystick ECUs capture analog inputs and buttons and publish them over CAN. The updated pin configuration with dedicated transceiver control pins (CAN_ME2107_EN_PIN and CAN_SPEED_MODE_PIN) provides better control over the CAN transceiver operation. Proper CAN topology, termination, and grounding are essential for reliable operation, especially with high-current solenoid loads.

## Appendices

### Pin Assignments and Peripherals
- CAN TX/RX: GPIO 5/4 (Motor Driver), GPIO 27/26 (Joystick).
- Transceiver Control: GPIO 16 (CAN_ME2107_EN), GPIO 23 (CAN_SPEED_MODE).
- WS2812 LED: GPIO 48 (Motor Driver), GPIO 4 (Joystick).
- I2C SDA/SCL: GPIO 21/22 for PCA9685.
- Joystick ADC: GPIO 32/33/34 for pots; buttons on GPIO 12/5 with internal pull-up.
- PCA9685 I2C addresses: 0x40 (primary), 0x41 (detected automatically).

**Section sources**
- [README.md:48-62](file://README.md#L48-L62)
- [platformio.ini:23-28](file://platformio.ini#L23-L28)
- [platformio.ini:38-45](file://platformio.ini#L38-L45)
- [platformio.ini:54-61](file://platformio.ini#L54-L61)
- [README.md:111-125](file://README.md#L111-L125)

### Power Supply and Load Characteristics
- PCA9685 operates on 5 V; ensure adequate current capacity for 16 MOSFET outputs.
- Solenoid coil inductance and peak current must be considered; use flyback diodes and appropriate wiring gauge.
- Ground planes under the motor driver PCB help minimize noise and voltage drops.

### Safety Considerations for High-Current Loads
- Implement a watchdog that disables solenoids after a timeout if no CAN command is received.
- Use separate power supplies or heavy-gauge wiring for solenoids to avoid brown-out conditions.
- Maintain a solid ground connection and avoid long ground loops near sensitive analog signals.
- Ensure proper transceiver enable timing to prevent bus contention during startup.

**Section sources**
- [README.md:105-111](file://README.md#L105-L111)
- [src/ecu_motor_driver.cpp:330-335](file://src/ecu_motor_driver.cpp#L330-L335)
- [src/ecu_joystick.cpp:190-197](file://src/ecu_joystick.cpp#L190-L197)

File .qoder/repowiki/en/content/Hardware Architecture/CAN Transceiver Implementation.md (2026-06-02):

# CAN Transceiver Implementation

<cite>
**Referenced Files in This Document**
- [README.md](file://README.md)
- [platformio.ini](file://platformio.ini)
- [main.cpp](file://src/main.cpp)
- [ecu_motor_driver.cpp](file://src/ecu_motor_driver.cpp)
- [ecu_motor_driver.h](file://src/ecu_motor_driver.h)
- [ecu_joystick.cpp](file://src/ecu_joystick.cpp)
- [ecu_joystick.h](file://src/ecu_joystick.h)
- [ForwarderCAN.h](file://lib/ForwarderCAN/ForwarderCAN.h)
- [ForwarderCAN.cpp](file://lib/ForwarderCAN/ForwarderCAN.cpp)
- [ForwarderConfig.h](file://lib/ForwarderConfig/ForwarderConfig.h)
- [ForwarderConfig.cpp](file://lib/ForwarderConfig/ForwarderConfig.cpp)
- [can_output.cpp](file://src/can_output.cpp)
- [can_output.h](file://src/can_output.h)
- [ota_webserver.cpp](file://src/ota_webserver.cpp)
- [ota_webserver.h](file://src/ota_webserver.h)
- [web_state.cpp](file://src/web_state.cpp)
- [web_state.h](file://src/web_state.h)
</cite>

## Table of Contents
1. [Introduction](#introduction)
2. [Project Structure](#project-structure)
3. [Core Components](#core-components)
4. [Architecture Overview](#architecture-overview)
5. [Detailed Component Analysis](#detailed-component-analysis)
6. [Dependency Analysis](#dependency-analysis)
7. [Performance Considerations](#performance-considerations)
8. [Troubleshooting Guide](#troubleshooting-guide)
9. [Conclusion](#conclusion)

## Introduction
This document describes the CAN bus implementation for the Forwarder CAN Controller using the built-in transceiver on the LilyGO T-CAN board. It explains the J1939-like protocol with 29-bit extended IDs, addressing scheme (0x20 for motor driver, 0x21 and 0x22 for joysticks), and the message structure including priority, data page, parameter group number (PGN), and source addresses. It documents the address claiming mechanism for collision avoidance, the heartbeat broadcast system, and the TWAI controller configuration and error handling. It also covers bus topology requirements, termination considerations, and signal integrity guidelines.

## Project Structure
The project is organized into:
- A shared library for CAN/J1939 abstraction and configuration
- Two ECU implementations (motor driver and joystick)
- An optional OTA web server for diagnostics and configuration
- Build environments configured per ECU type and address

```mermaid
graph TB
A["main.cpp<br/>Entry point"] --> B["ecu_motor_driver.cpp<br/>Motor driver ECU"]
A --> C["ecu_joystick.cpp<br/>Joystick ECU"]
B --> D["ForwarderCAN.cpp/.h<br/>TWAI/J1939 stack"]
C --> D
B --> E["ForwarderConfig.cpp/.h<br/>NVS-backed config"]
C --> E
B --> F["can_output.cpp/.h<br/>CAN-triggered GPIO"]
B --> G["ota_webserver.cpp/.h<br/>Optional OTA UI"]
C --> G
D --> H["TWAI driver<br/>ESP-IDF"]
```

**Diagram sources**
- [main.cpp:19-31](file://src/main.cpp#L19-L31)
- [ecu_motor_driver.cpp:290-325](file://src/ecu_motor_driver.cpp#L290-L325)
- [ecu_joystick.cpp:159-192](file://src/ecu_joystick.cpp#L159-L192)
- [ForwarderCAN.cpp:13-52](file://lib/ForwarderCAN/ForwarderCAN.cpp#L13-L52)
- [ForwarderConfig.cpp:56-104](file://lib/ForwarderConfig/ForwarderConfig.cpp#L56-L104)
- [can_output.cpp:7-19](file://src/can_output.cpp#L7-L19)
- [ota_webserver.cpp:766-791](file://src/ota_webserver.cpp#L766-L791)

**Section sources**
- [README.md:112-126](file://README.md#L112-L126)
- [platformio.ini:1-80](file://platformio.ini#L1-L80)
- [main.cpp:11-17](file://src/main.cpp#L11-L17)

## Core Components
- TWAI/J1939 stack encapsulated in ForwarderCAN:
  - Implements 29-bit J1939-like ID layout with priority, data page, PF/PDU format, PS/DA, and SA
  - Provides address claiming, arbitration, and bus-off recovery
  - Exposes send/receive APIs and statistics
- ECU implementations:
  - Motor driver ECU: controls solenoids via PCA9685, processes joystick inputs, and broadcasts heartbeat
  - Joystick ECU: reads pots/buttons and publishes telemetry
- Configuration and persistence:
  - ForwarderConfig stores address overrides, axis mapping, and CAN output rules in NVS
- CAN-triggered GPIO outputs:
  - Rules to toggle or momentary pulse external GPIOs based on matching PF/SA
- Optional OTA web server:
  - Diagnostics dashboard, module discovery, remote configuration, and firmware updates

**Section sources**
- [ForwarderCAN.h:66-120](file://lib/ForwarderCAN/ForwarderCAN.h#L66-L120)
- [ForwarderCAN.cpp:13-52](file://lib/ForwarderCAN/ForwarderCAN.cpp#L13-L52)
- [ecu_motor_driver.cpp:290-325](file://src/ecu_motor_driver.cpp#L290-L325)
- [ecu_joystick.cpp:159-192](file://src/ecu_joystick.cpp#L159-L192)
- [ForwarderConfig.h:64-92](file://lib/ForwarderConfig/ForwarderConfig.h#L64-L92)
- [ForwarderConfig.cpp:56-104](file://lib/ForwarderConfig/ForwarderConfig.cpp#L56-L104)
- [can_output.cpp:7-19](file://src/can_output.cpp#L7-L19)
- [ota_webserver.cpp:766-791](file://src/ota_webserver.cpp#L766-L791)

## Architecture Overview
The system uses a J1939-like 29-bit ID layout with:
- Priority: 3 bits
- Data Page: 1 bit
- PDU Format (PF): 8 bits
- PDU Specific (PS) or Destination Address (DA): 8 bits
- Source Address (SA): 8 bits

Address claiming uses PF 0xEE (Address Claimed) and PF 0xEA (Request Address Claimed). Heartbeat broadcasts occur every second. The TWAI driver is configured via platform-specific timing configurations and supports bus-off recovery.

```mermaid
sequenceDiagram
participant MD as "Motor Driver ECU"
participant JC1 as "Joystick 1 ECU"
participant JC2 as "Joystick 2 ECU"
participant CAN as "ForwarderCAN"
participant TWAI as "TWAI Driver"
Note over MD,CAN : Startup address claiming
MD->>CAN : begin(tx, rx, bitrate)
CAN->>TWAI : driver_install/start
CAN->>CAN : tryClaimAddress()
CAN->>TWAI : send Address Claimed (PF=0xEE)
Note over CAN,TWAI : Wait up to 250 ms for conflicts
Note over MD,JC1 : Normal operation
JC1->>CAN : sendBroadcast(PF_JOYSTICK_POT1/2/3, payload)
JC1->>CAN : sendBroadcast(PF_JOYSTICK_BUTTONS, payload)
MD->>CAN : receive()
CAN->>MD : processCAN()
MD->>CAN : sendBroadcast(PF_HEARTBEAT, payload)
MD->>CAN : sendBroadcast(PF_SOLENOID_CMD, duty cycle)
```

**Diagram sources**
- [ForwarderCAN.cpp:13-52](file://lib/ForwarderCAN/ForwarderCAN.cpp#L13-L52)
- [ForwarderCAN.cpp:54-61](file://lib/ForwarderCAN/ForwarderCAN.cpp#L54-L61)
- [ForwarderCAN.cpp:63-77](file://lib/ForwarderCAN/ForwarderCAN.cpp#L63-L77)
- [ecu_motor_driver.cpp:184-275](file://src/ecu_motor_driver.cpp#L184-L275)
- [ecu_joystick.cpp:114-144](file://src/ecu_joystick.cpp#L114-L144)

**Section sources**
- [ForwarderCAN.h:7-34](file://lib/ForwarderCAN/ForwarderCAN.h#L7-L34)
- [ForwarderCAN.cpp:79-119](file://lib/ForwarderCAN/ForwarderCAN.cpp#L79-L119)
- [ecu_motor_driver.cpp:277-288](file://src/ecu_motor_driver.cpp#L277-L288)
- [ecu_joystick.cpp:146-157](file://src/ecu_joystick.cpp#L146-L157)

## Detailed Component Analysis

### TWAI Controller and J1939-like Protocol
- ID layout and macros define priority, data page, PF, PS/DA, and SA fields
- Custom PF constants encode joystick telemetry, LED control, solenoid commands, identification, address setting, configuration, and heartbeat
- Send/receive APIs construct 29-bit extended IDs and manage data length
- Address claiming:
  - Sends Address Claimed (PF 0xEE) to DA 0xFF with 8-byte NAME
  - Waits up to 250 ms; if no conflict, transitions to claimed
  - On conflict, arbitration compares NAME bytes; lower value wins
- Bus-off recovery:
  - Periodic status polling detects bus-off state
  - Initiates recovery automatically

```mermaid
classDiagram
class ForwarderCAN {
+begin(txPin, rxPin, bitrate) bool
+loop() void
+send(pf, ps, data, len, priority) bool
+sendBroadcast(pf, data, len, priority) bool
+receive(msg, timeoutMs) bool
+isOnline() bool
+getAddress() uint8_t
+getTxCount() uint32_t
+getRxCount() uint32_t
+getErrorCount() uint32_t
-tryClaimAddress() void
-sendAddressClaimed() void
-processNetworkManagement(msg) void
}
```

**Diagram sources**
- [ForwarderCAN.h:66-120](file://lib/ForwarderCAN/ForwarderCAN.h#L66-L120)
- [ForwarderCAN.cpp:13-52](file://lib/ForwarderCAN/ForwarderCAN.cpp#L13-L52)
- [ForwarderCAN.cpp:54-119](file://lib/ForwarderCAN/ForwarderCAN.cpp#L54-L119)

**Section sources**
- [ForwarderCAN.h:7-34](file://lib/ForwarderCAN/ForwarderCAN.h#L7-L34)
- [ForwarderCAN.h:38-51](file://lib/ForwarderCAN/ForwarderCAN.h#L38-L51)
- [ForwarderCAN.cpp:13-52](file://lib/ForwarderCAN/ForwarderCAN.cpp#L13-L52)
- [ForwarderCAN.cpp:54-119](file://lib/ForwarderCAN/ForwarderCAN.cpp#L54-L119)

### Address Claiming Mechanism
- Initial state starts claiming with preferred address
- Sends Address Claimed (PF 0xEE, DA 0xFF) and waits
- If no conflicting claim arrives within 250 ms, address is claimed
- If conflict occurs, compares NAME bytes; lower value wins
- Retries up to 5 attempts; after that, tries an alternate address derived from NAME hash

```mermaid
flowchart TD
Start(["Start"]) --> Init["Set preferred address<br/>Enter CLAIMING state"]
Init --> SendClaim["Send Address Claimed (PF=0xEE, DA=0xFF)"]
SendClaim --> Wait["Wait up to 250 ms"]
Wait --> Conflict{"Conflict received?"}
Conflict --> |No| Claimed["Transition to CLAIMED"]
Conflict --> |Yes| Arbitrate["Compare NAME bytes"]
Arbitrate --> LowerWins{"Lower NAME wins?"}
LowerWins --> |Yes| CannotClaim["Set state=CANNOT_CLAIM<br/>Retry after 1000 ms"]
LowerWins --> |No| Reclaim["Re-send Address Claimed"]
CannotClaim --> Retry{"Attempts < 5?"}
Retry --> |Yes| Init
Retry --> |No| Alternate["Compute alternate address from NAME hash<br/>Reset attempts"]
Alternate --> Init
```

**Diagram sources**
- [ForwarderCAN.cpp:54-119](file://lib/ForwarderCAN/ForwarderCAN.cpp#L54-L119)
- [ForwarderCAN.cpp:121-142](file://lib/ForwarderCAN/ForwarderCAN.cpp#L121-L142)

**Section sources**
- [ForwarderCAN.cpp:54-119](file://lib/ForwarderCAN/ForwarderCAN.cpp#L54-L119)
- [ForwarderCAN.cpp:121-142](file://lib/ForwarderCAN/ForwarderCAN.cpp#L121-L142)

### Heartbeat Broadcast System
- All ECUs broadcast a heartbeat every 1000 ms when online
- Heartbeat payload includes online status, uptime, RX/TX counts, and device-specific flags
- Motor driver heartbeat encodes PCA count and channel availability
- Joystick heartbeat encodes joystick identity and counters

```mermaid
sequenceDiagram
participant MD as "Motor Driver"
participant JC as "Joystick"
participant CAN as "ForwarderCAN"
loop Every 1000 ms
MD->>CAN : sendBroadcast(PF_HEARTBEAT, payload)
JC->>CAN : sendBroadcast(PF_HEARTBEAT, payload)
end
```

**Diagram sources**
- [ecu_motor_driver.cpp:277-288](file://src/ecu_motor_driver.cpp#L277-L288)
- [ecu_joystick.cpp:146-157](file://src/ecu_joystick.cpp#L146-L157)

**Section sources**
- [ecu_motor_driver.cpp:277-288](file://src/ecu_motor_driver.cpp#L277-L288)
- [ecu_joystick.cpp:146-157](file://src/ecu_joystick.cpp#L146-L157)

### CAN Message Structure and Addressing Scheme
- 29-bit extended ID layout:
  - Priority: bits 28-26
  - Data Page: bit 25
  - PDU Format (PF): bits 23-16
  - PDU Specific (PS) or Destination Address (DA): bits 15-8
  - Source Address (SA): bits 7-0
- Addressing scheme:
  - Motor driver: SA 0x20
  - Joystick 1: SA 0x21
  - Joystick 2: SA 0x22
- PF definitions:
  - Joystick telemetry: PF 0x10–0x13
  - LED control: PF 0x20
  - Solenoid command: PF 0x21
  - Identify: PF 0x22
  - Set address: PF 0x23
  - Config: PF 0x24–0x26
  - Heartbeat: PF 0x30

**Section sources**
- [ForwarderCAN.h:7-34](file://lib/ForwarderCAN/ForwarderCAN.h#L7-L34)
- [ForwarderCAN.h:38-51](file://lib/ForwarderCAN/ForwarderCAN.h#L38-L51)
- [README.md:10-14](file://README.md#L10-L14)
- [platformio.ini:17-30](file://platformio.ini#L17-L30)
- [platformio.ini:31-62](file://platformio.ini#L31-L62)

### Motor Driver ECU
- Initializes PCA9685 PWM drivers and onboard LED
- Sets up ForwarderCAN with preferred address 0x20 and ECU name
- Receives joystick pots/buttons and updates solenoid outputs
- Supports LED color control, identify, and address setting via CAN
- Broadcasts heartbeat and handles safety timeout to turn off outputs if no command received within 500 ms

```mermaid
flowchart TD
MStart["Initialize PCA9685 and LED"] --> CANInit["Initialize ForwarderCAN (SA=0x20)"]
CANInit --> Loop["Main loop"]
Loop --> Receive["Receive and process CAN"]
Receive --> UpdateAxes["Map joystick pots to solenoids"]
UpdateAxes --> Safety{"Safety timeout elapsed?"}
Safety --> |Yes| AllOff["Turn off all solenoids"]
Safety --> |No| Continue["Continue normal operation"]
Continue --> Heartbeat["Send heartbeat every 1000 ms"]
Heartbeat --> Loop
```

**Diagram sources**
- [ecu_motor_driver.cpp:290-325](file://src/ecu_motor_driver.cpp#L290-L325)
- [ecu_motor_driver.cpp:184-275](file://src/ecu_motor_driver.cpp#L184-L275)
- [ecu_motor_driver.cpp:327-352](file://src/ecu_motor_driver.cpp#L327-L352)

**Section sources**
- [ecu_motor_driver.cpp:290-325](file://src/ecu_motor_driver.cpp#L290-L325)
- [ecu_motor_driver.cpp:184-275](file://src/ecu_motor_driver.cpp#L184-L275)
- [ecu_motor_driver.cpp:327-352](file://src/ecu_motor_driver.cpp#L327-L352)

### Joystick ECU
- Initializes inputs, onboard LED, and ForwarderCAN with preferred address 0x21 or 0x22
- Publishes joystick pots/buttons periodically and on change
- Responds to LED color, identify, and address setting commands
- Broadcasts heartbeat every 1000 ms

```mermaid
sequenceDiagram
participant JC as "Joystick ECU"
participant CAN as "ForwarderCAN"
loop Normal operation
JC->>JC : readInputs()
JC->>CAN : sendBroadcast(PF_JOYSTICK_POT1/2/3, payload)
JC->>CAN : sendBroadcast(PF_JOYSTICK_BUTTONS, payload)
CAN->>JC : receive()
JC->>CAN : processCAN()
alt 1000 ms elapsed
JC->>CAN : sendBroadcast(PF_HEARTBEAT, payload)
end
end
```

**Diagram sources**
- [ecu_joystick.cpp:159-192](file://src/ecu_joystick.cpp#L159-L192)
- [ecu_joystick.cpp:114-144](file://src/ecu_joystick.cpp#L114-L144)
- [ecu_joystick.cpp:194-236](file://src/ecu_joystick.cpp#L194-L236)

**Section sources**
- [ecu_joystick.cpp:159-192](file://src/ecu_joystick.cpp#L159-L192)
- [ecu_joystick.cpp:114-144](file://src/ecu_joystick.cpp#L114-L144)
- [ecu_joystick.cpp:194-236](file://src/ecu_joystick.cpp#L194-L236)

### CAN-Triggered GPIO Outputs
- Rules allow reacting to incoming CAN messages by toggling or momentary pulsing a GPIO pin
- Matching criteria include PF and optional SA
- Momentary mode pulses output for a configurable duration

```mermaid
flowchart TD
RStart["CAN message received"] --> Match["Match rules by PF/SA"]
Match --> Mode{"Mode: Toggle or Momentary"}
Mode --> |Toggle| Toggle["Flip output state"]
Mode --> |Momentary| Pulse["Set HIGH, start timer"]
Pulse --> Timer["Wait until timeout"]
Timer --> Release["Set LOW"]
```

**Diagram sources**
- [can_output.cpp:29-49](file://src/can_output.cpp#L29-L49)
- [can_output.cpp:51-61](file://src/can_output.cpp#L51-L61)

**Section sources**
- [can_output.cpp:7-19](file://src/can_output.cpp#L7-L19)
- [can_output.cpp:29-49](file://src/can_output.cpp#L29-L49)
- [can_output.cpp:51-61](file://src/can_output.cpp#L51-L61)
- [ForwarderConfig.h:28-39](file://lib/ForwarderConfig/ForwarderConfig.h#L28-L39)

### Configuration and Persistence
- Address override persisted in NVS under "forced_addr"
- Motor mapping stored as packed 8-byte entries per axis
- CAN output rules stored as packed 8-byte entries
- Defaults loaded when NVS keys are missing

**Section sources**
- [ForwarderConfig.h:64-92](file://lib/ForwarderConfig/ForwarderConfig.h#L64-L92)
- [ForwarderConfig.cpp:61-74](file://lib/ForwarderConfig/ForwarderConfig.cpp#L61-L74)
- [ForwarderConfig.cpp:76-104](file://lib/ForwarderConfig/ForwarderConfig.cpp#L76-L104)
- [ForwarderConfig.cpp:119-127](file://lib/ForwarderConfig/ForwarderConfig.cpp#L119-L127)
- [ForwarderConfig.cpp:129-159](file://lib/ForwarderConfig/ForwarderConfig.cpp#L129-L159)
- [ForwarderConfig.cpp:171-183](file://lib/ForwarderConfig/ForwarderConfig.cpp#L171-L183)

### OTA Web Server (Optional)
- Starts Wi-Fi AP and mDNS service
- Serves a dashboard showing joystick inputs, solenoid outputs, CAN stats, and discovered modules
- Allows remote identification, address changes, and firmware updates
- Scans heartbeats to discover modules and infer ECU types

**Section sources**
- [ota_webserver.cpp:766-791](file://src/ota_webserver.cpp#L766-L791)
- [ota_webserver.cpp:506-563](file://src/ota_webserver.cpp#L506-L563)
- [ota_webserver.cpp:740-761](file://src/ota_webserver.cpp#L740-L761)

## Dependency Analysis
The ECU implementations depend on the shared ForwarderCAN library and configuration manager. The motor driver additionally depends on PCA9685 PWM drivers and NeoPixel LEDs. The OTA web server depends on Wi-Fi, mDNS, and embedded HTML/CSS/JS.

```mermaid
graph LR
MD["ecu_motor_driver.cpp"] --> FC["ForwarderCAN.cpp/.h"]
JC["ecu_joystick.cpp"] --> FC
MD --> CFG["ForwarderConfig.cpp/.h"]
JC --> CFG
MD --> PCA["PCA9685 (external)"]
MD --> LED["NeoPixel (external)"]
OTA["ota_webserver.cpp/.h"] --> MD
OTA --> JC
FC --> TWAI["ESP-IDF TWAI driver"]
```

**Diagram sources**
- [ecu_motor_driver.cpp:8-12](file://src/ecu_motor_driver.cpp#L8-L12)
- [ecu_joystick.cpp:5-9](file://src/ecu_joystick.cpp#L5-L9)
- [ForwarderCAN.cpp:13-52](file://lib/ForwarderCAN/ForwarderCAN.cpp#L13-L52)
- [ota_webserver.cpp:5-12](file://src/ota_webserver.cpp#L5-L12)

**Section sources**
- [ecu_motor_driver.cpp:8-12](file://src/ecu_motor_driver.cpp#L8-L12)
- [ecu_joystick.cpp:5-9](file://src/ecu_joystick.cpp#L5-L9)
- [ForwarderCAN.cpp:13-52](file://lib/ForwarderCAN/ForwarderCAN.cpp#L13-L52)
- [ota_webserver.cpp:5-12](file://src/ota_webserver.cpp#L5-L12)

## Performance Considerations
- TWAI queue sizes are tuned (tx queue depth 16, rx queue depth 32) to handle bursts of joystick telemetry and heartbeat traffic
- Heartbeat interval balances visibility with bandwidth usage
- Safety timeout prevents unintended actuator activation if CAN communication fails
- Bus-off recovery avoids manual intervention by automatically re-entering the bus when detected

[No sources needed since this section provides general guidance]

## Troubleshooting Guide
- CAN initialization failure:
  - The motor driver flashes LED and loops if ForwarderCAN begin() fails
  - Verify wiring and platformio.ini pin assignments for LilyGO T-CAN defaults (TX=5, RX=4)
- Address conflicts:
  - If claiming fails, the device retries up to 5 times; after that it tries an alternate address derived from NAME hash
  - Use the OTA dashboard to identify modules and adjust addresses if needed
- Bus-off state:
  - The stack detects bus-off and initiates recovery automatically; persistent error counters track occurrences
- Heartbeat monitoring:
  - Use the OTA dashboard to confirm presence and uptime of other ECUs
- Safety timeout:
  - If no joystick commands are received for 500 ms, motor driver turns off solenoids

**Section sources**
- [ecu_motor_driver.cpp:305-316](file://src/ecu_motor_driver.cpp#L305-L316)
- [ForwarderCAN.cpp:82-89](file://lib/ForwarderCAN/ForwarderCAN.cpp#L82-L89)
- [ForwarderCAN.cpp:98-109](file://lib/ForwarderCAN/ForwarderCAN.cpp#L98-L109)
- [ota_webserver.cpp:740-761](file://src/ota_webserver.cpp#L740-L761)
- [ecu_motor_driver.cpp:332-337](file://src/ecu_motor_driver.cpp#L332-L337)

## Conclusion
The Forwarder CAN Controller implements a robust J1939-like CAN bus system on the LilyGO T-CAN board using the ESP32-S3 TWAI controller. It features deterministic addressing (0x20, 0x21, 0x22), reliable address claiming with arbitration, periodic heartbeat broadcasting, and practical safety mechanisms. The modular design separates protocol logic (ForwarderCAN), configuration (NVS), and ECU-specific behavior, enabling maintainable and extensible operation across multiple ECUs.

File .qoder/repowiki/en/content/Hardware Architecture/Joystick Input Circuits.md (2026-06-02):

# Joystick Input Circuits

<cite>
**Referenced Files in This Document**
- [README.md](file://README.md)
- [platformio.ini](file://platformio.ini)
- [src/main.cpp](file://src/main.cpp)
- [src/ecu_joystick.h](file://src/ecu_joystick.h)
- [src/ecu_joystick.cpp](file://src/ecu_joystick.cpp)
- [lib/ForwarderCAN/ForwarderCAN.h](file://lib/ForwarderCAN/ForwarderCAN.h)
- [lib/ForwarderConfig/ForwarderConfig.h](file://lib/ForwarderConfig/ForwarderConfig.h)
- [src/ecu_motor_driver.cpp](file://src/ecu_motor_driver.cpp)
- [src/web_state.h](file://src/web_state.h)
</cite>

## Table of Contents
1. [Introduction](#introduction)
2. [Project Structure](#project-structure)
3. [Core Components](#core-components)
4. [Architecture Overview](#architecture-overview)
5. [Detailed Component Analysis](#detailed-component-analysis)
6. [Dependency Analysis](#dependency-analysis)
7. [Performance Considerations](#performance-considerations)
8. [Troubleshooting Guide](#troubleshooting-guide)
9. [Conclusion](#conclusion)
10. [Appendices](#appendices)

## Introduction
This document describes the joystick input circuitry and firmware implementation for the Forwarder CAN Controller. It covers:
- Three potentiometer channels and two button inputs per controller
- ESP32 ADC configuration for 10-bit resolution and reference attenuation
- Signal conditioning considerations for potentiometer inputs
- Button configuration with active-low logic and internal pull-ups
- Software debouncing behavior and thresholds
- Calibration procedures for zero positions and travel limits
- CAN message format for joystick data, including 10-bit value encoding and button state reporting
- Input sensitivity and deadband configuration for operator feedback

## Project Structure
The joystick ECU is implemented as a PlatformIO environment with build flags selecting the ECU type. The joystick firmware reads analog inputs, processes button states, and broadcasts CAN messages. The motor driver ECU consumes joystick data to drive solenoids.

```mermaid
graph TB
subgraph "Build Environments"
JOY1["joystick1<br/>ECU_JOYSTICK_ID=1<br/>POT1_PIN=32<br/>POT2_PIN=33<br/>BTN1_PIN=12<br/>BTN2_PIN=18"]
JOY2["joystick2<br/>ECU_JOYSTICK_ID=2<br/>POT1_PIN=32<br/>POT2_PIN=33<br/>BTN1_PIN=12<br/>BTN2_PIN=18"]
MOTOR["motor_driver<br/>PCA9685 I2C<br/>Solenoid Outputs"]
end
subgraph "Joystick ECU"
MAIN["main.cpp<br/>Entry point"]
ECUJ["ecu_joystick.cpp/.h<br/>ADC, Buttons, CAN Tx"]
CANLIB["ForwarderCAN.h<br/>CAN IDs/PF defs"]
CFG["ForwarderConfig.h<br/>Axis/Deadband Config"]
end
subgraph "Motor Driver ECU"
ECUM["ecu_motor_driver.cpp<br/>Joystick Data Consumer"]
WEB["web_state.h<br/>Shared state"]
end
MAIN --> ECUJ
ECUJ --> CANLIB
ECUJ --> CFG
ECUM --> CANLIB
ECUM --> WEB
JOY1 --> ECUJ
JOY2 --> ECUJ
MOTOR --> ECUM
```

**Diagram sources**
- [platformio.ini:31-61](file://platformio.ini#L31-L61)
- [src/main.cpp:11-17](file://src/main.cpp#L11-L17)
- [src/ecu_joystick.cpp:159-192](file://src/ecu_joystick.cpp#L159-L192)
- [lib/ForwarderCAN/ForwarderCAN.h:38-50](file://lib/ForwarderCAN/ForwarderCAN.h#L38-L50)
- [lib/ForwarderConfig/ForwarderConfig.h:41-57](file://lib/ForwarderConfig/ForwarderConfig.h#L41-L57)
- [src/ecu_motor_driver.cpp:184-275](file://src/ecu_motor_driver.cpp#L184-L275)
- [src/web_state.h:10-22](file://src/web_state.h#L10-L22)

**Section sources**
- [platformio.ini:1-80](file://platformio.ini#L1-L80)
- [src/main.cpp:1-32](file://src/main.cpp#L1-L32)

## Core Components
- Joystick ECU: Reads two analog channels (POT1, POT2) and two buttons (BTN1, BTN2), configures ADC and CAN, and sends periodic joystick data.
- CAN Library: Defines J1939-like IDs and PF values for joystick messages.
- Motor Driver ECU: Receives joystick data, applies deadband mapping, and controls solenoids.
- Configuration Manager: Stores axis mapping and deadband settings for operator feedback tuning.

Key responsibilities:
- ADC sampling and threshold-based transmission
- Button state aggregation and broadcast
- CAN framing and broadcasting
- Deadband mapping and PWM scaling

**Section sources**
- [src/ecu_joystick.cpp:63-68](file://src/ecu_joystick.cpp#L63-L68)
- [src/ecu_joystick.cpp:106-112](file://src/ecu_joystick.cpp#L106-L112)
- [lib/ForwarderCAN/ForwarderCAN.h:38-50](file://lib/ForwarderCAN/ForwarderCAN.h#L38-L50)
- [src/ecu_motor_driver.cpp:101-135](file://src/ecu_motor_driver.cpp#L101-L135)
- [lib/ForwarderConfig/ForwarderConfig.h:41-57](file://lib/ForwarderConfig/ForwarderConfig.h#L41-L57)

## Architecture Overview
The joystick ECU samples analog inputs and broadcasts them as 10-bit values over CAN. The motor driver ECU receives these values, applies deadband mapping, and sets PWM outputs to solenoids. The system uses J1939-like 29-bit IDs with PF values dedicated to joystick data.

```mermaid
sequenceDiagram
participant POT as "Potentiometer Inputs"
participant ADC as "ESP32 ADC"
participant ECU as "Joystick ECU"
participant CAN as "ForwarderCAN"
participant MD as "Motor Driver ECU"
POT->>ADC : "Analog signals"
ADC-->>ECU : "Raw 10-bit values"
ECU->>ECU : "Compare with previous values"
ECU->>CAN : "sendBroadcast(PF_JOYSTICK_POT1/2, 2 bytes)"
CAN-->>MD : "Joystick data frames"
MD->>MD : "Apply deadband mapping"
MD->>MD : "Set PWM outputs"
```

**Diagram sources**
- [src/ecu_joystick.cpp:63-68](file://src/ecu_joystick.cpp#L63-L68)
- [src/ecu_joystick.cpp:194-236](file://src/ecu_joystick.cpp#L194-L236)
- [lib/ForwarderCAN/ForwarderCAN.h:38-50](file://lib/ForwarderCAN/ForwarderCAN.h#L38-L50)
- [src/ecu_motor_driver.cpp:191-204](file://src/ecu_motor_driver.cpp#L191-L204)

## Detailed Component Analysis

### Analog Input Configuration (ESP32 ADC)
- Resolution: 10-bit ADC configured via the MCU’s ADC resolution setting.
- Attenuation: 11 dB attenuation selected to extend input range suitable for typical 3.3 V supply and potentiometer rails.
- Sampling pins: POT1_PIN and POT2_PIN are sampled in the joystick ECU.
- Reference considerations: The ADC reference is internally referenced to 3.3 V; the 10-bit range maps to approximately 0–1023 counts.

Operational behavior:
- ADC resolution and attenuation are set during initialization.
- Values are read synchronously in the loop and compared against previous values with a small hysteresis threshold before transmission.

**Section sources**
- [src/ecu_joystick.cpp:163-164](file://src/ecu_joystick.cpp#L163-L164)
- [src/ecu_joystick.cpp:63-68](file://src/ecu_joystick.cpp#L63-L68)
- [README.md:57-61](file://README.md#L57-L61)

### Signal Conditioning for Potentiometer Inputs
- Filtering and noise reduction: The joystick firmware does not implement explicit analog filtering. Noise immunity relies on:
  - MCU ADC characteristics and sampling timing
  - Mechanical stability of potentiometer wafers
  - CAN-level filtering and error handling in the receiving ECU
- Threshold-based transmission: Values are sent only when they change beyond a small threshold, reducing CAN traffic and mitigating transient noise effects.

**Section sources**
- [src/ecu_joystick.cpp:200-209](file://src/ecu_joystick.cpp#L200-L209)
- [src/ecu_joystick.cpp:218-225](file://src/ecu_joystick.cpp#L218-L225)

### Button Input Configuration (Active-Low Logic)
- Pins: BTN1_PIN and BTN2_PIN are configured as inputs with internal pull-up resistors.
- Logic: Buttons are active-low; the firmware reads the pin state and treats LOW as pressed.
- Debounce: Software debounce is implemented via a threshold-based approach:
  - Button state is aggregated into a single byte.
  - A change in the aggregated state triggers immediate transmission.
  - A periodic broadcast occurs at intervals to ensure liveness even when idle.

```mermaid
flowchart TD
Start(["Button Read"]) --> ReadPins["Read BTN1/BTN2"]
ReadPins --> Aggregate["Aggregate bits into byte"]
Aggregate --> ComparePrev{"State changed?"}
ComparePrev --> |Yes| Send["Send PF_JOYSTICK_BUTTONS"]
ComparePrev --> |No| PeriodicCheck["Wait until periodic interval"]
PeriodicCheck --> ForceSend["Force send if no change"]
Send --> End(["Done"])
ForceSend --> End
```

**Diagram sources**
- [src/ecu_joystick.cpp:66-67](file://src/ecu_joystick.cpp#L66-L67)
- [src/ecu_joystick.cpp:210-217](file://src/ecu_joystick.cpp#L210-L217)
- [src/ecu_joystick.cpp:220-224](file://src/ecu_joystick.cpp#L220-L224)

**Section sources**
- [src/ecu_joystick.cpp:165-166](file://src/ecu_joystick.cpp#L165-L166)
- [src/ecu_joystick.cpp:66-67](file://src/ecu_joystick.cpp#L66-L67)
- [src/ecu_joystick.cpp:210-217](file://src/ecu_joystick.cpp#L210-L217)

### CAN Message Transmission Format for Joystick Data
- Potentiometer values:
  - PF values: PF_JOYSTICK_POT1, PF_JOYSTICK_POT2
  - Payload: Two bytes, LSB then MSB of the 10-bit value
- Button states:
  - PF value: PF_JOYSTICK_BUTTONS
  - Payload: One byte with bit 0 for BTN1 and bit 1 for BTN2
- Broadcasting:
  - Messages are broadcast to all ECUs (destination address 0xFF)
  - Priority and rate limiting are handled by the CAN library and loop scheduling

```mermaid
sequenceDiagram
participant ECU as "Joystick ECU"
participant CAN as "ForwarderCAN"
participant NET as "CAN Bus"
participant MD as "Motor Driver ECU"
ECU->>ECU : "readInputs()"
ECU->>ECU : "compare thresholds"
ECU->>CAN : "sendBroadcast(PF_JOYSTICK_POT1, [LSB, MSB])"
ECU->>CAN : "sendBroadcast(PF_JOYSTICK_POT2, [LSB, MSB])"
ECU->>CAN : "sendBroadcast(PF_JOYSTICK_BUTTONS, [buttons])"
CAN-->>NET : "Frame with J1939-like ID"
NET-->>MD : "Frames received"
MD->>MD : "Store values and update outputs"
```

**Diagram sources**
- [src/ecu_joystick.cpp:99-112](file://src/ecu_joystick.cpp#L99-L112)
- [lib/ForwarderCAN/ForwarderCAN.h:38-50](file://lib/ForwarderCAN/ForwarderCAN.h#L38-L50)
- [src/ecu_motor_driver.cpp:191-204](file://src/ecu_motor_driver.cpp#L191-L204)

**Section sources**
- [src/ecu_joystick.cpp:99-112](file://src/ecu_joystick.cpp#L99-L112)
- [lib/ForwarderCAN/ForwarderCAN.h:38-50](file://lib/ForwarderCAN/ForwarderCAN.h#L38-L50)
- [README.md:35-41](file://README.md#L35-L41)

### Calibration Procedures
Calibration is performed at the receiving end (motor driver ECU) using deadband configuration:
- Zero position: Set deadbandMin equal to the expected center value for the axis.
- Travel limits: Set deadbandMax to define the end-stop region.
- Bidirectional operation: Enable bidirectional mapping to reverse direction below deadbandMin.
- PWM scaling: Configure min/max PWM values to adjust actuator response.

The configuration is stored persistently and transported over CAN for distribution.

```mermaid
flowchart TD
CalStart["Start Calibration"] --> Center["Record Center Value"]
Center --> MinLimit["Record Minimum Travel Value"]
MinLimit --> MaxLimit["Record Maximum Travel Value"]
MaxLimit --> Deadband["Set deadbandMin/deadbandMax"]
Deadband --> PWM["Set PWM min/max"]
PWM --> Save["Save to NVS via CAN"]
Save --> Apply["Apply on Motor Driver ECU"]
```

**Diagram sources**
- [lib/ForwarderConfig/ForwarderConfig.h:41-57](file://lib/ForwarderConfig/ForwarderConfig.h#L41-L57)
- [src/ecu_motor_driver.cpp:101-135](file://src/ecu_motor_driver.cpp#L101-L135)

**Section sources**
- [lib/ForwarderConfig/ForwarderConfig.h:41-57](file://lib/ForwarderConfig/ForwarderConfig.h#L41-L57)
- [src/ecu_motor_driver.cpp:101-135](file://src/ecu_motor_driver.cpp#L101-L135)

### Input Sensitivity Adjustment and Deadband Configuration
- Deadband concept: A region around the center where no output is produced to reduce chatter.
- Bidirectional mapping: Allows reverse operation below deadbandMin and forward above deadbandMax.
- PWM scaling: Converts mapped values to 12-bit PWM for PCA9685 outputs.
- Tuning: Adjust deadbandMin/deadbandMax and PWM min/max to optimize operator feel.

**Section sources**
- [lib/ForwarderConfig/ForwarderConfig.h:41-57](file://lib/ForwarderConfig/ForwarderConfig.h#L41-L57)
- [src/ecu_motor_driver.cpp:101-135](file://src/ecu_motor_driver.cpp#L101-L135)

## Dependency Analysis
- Joystick ECU depends on:
  - ForwarderCAN for CAN messaging
  - ForwarderConfig for persistent configuration storage
  - ESP32 ADC and GPIO APIs for input sampling
- Motor Driver ECU depends on:
  - ForwarderCAN for receiving joystick data
  - ForwarderConfig for axis mapping and deadband settings
  - PCA9685 drivers for PWM output control

```mermaid
graph LR
ECUJ["ecu_joystick.cpp"] --> CANLIB["ForwarderCAN.h"]
ECUJ --> CFG["ForwarderConfig.h"]
ECUM["ecu_motor_driver.cpp"] --> CANLIB
ECUM --> CFG
ECUM --> WEB["web_state.h"]
```

**Diagram sources**
- [src/ecu_joystick.cpp:5-9](file://src/ecu_joystick.cpp#L5-L9)
- [lib/ForwarderCAN/ForwarderCAN.h:38-50](file://lib/ForwarderCAN/ForwarderCAN.h#L38-L50)
- [lib/ForwarderConfig/ForwarderConfig.h:64-91](file://lib/ForwarderConfig/ForwarderConfig.h#L64-L91)
- [src/ecu_motor_driver.cpp:8-12](file://src/ecu_motor_driver.cpp#L8-L12)
- [src/web_state.h:10-17](file://src/web_state.h#L10-L17)

**Section sources**
- [src/ecu_joystick.cpp:5-9](file://src/ecu_joystick.cpp#L5-L9)
- [src/ecu_motor_driver.cpp:8-12](file://src/ecu_motor_driver.cpp#L8-L12)

## Performance Considerations
- ADC sampling and CAN throughput:
  - 10-bit resolution provides sufficient granularity for joystick control.
  - Threshold-based transmission reduces CAN load.
  - Periodic re-broadcast ensures liveness without continuous traffic.
- Button debounce:
  - Software threshold prevents spurious transmissions.
- Deadband mapping:
  - Reduces noise sensitivity near center.
  - Bidirectional mapping improves operator feedback.

[No sources needed since this section provides general guidance]

## Troubleshooting Guide
- No CAN messages received:
  - Verify CAN wiring and transceiver enable pin configuration.
  - Confirm address claiming succeeded and ECU is online.
- Buttons not responding:
  - Ensure pins are configured with internal pull-up and wired to ground when pressed.
  - Check for short circuits or floating inputs.
- Potentiometer jitter:
  - Increase the threshold delta for potentiometer values.
  - Verify power supply stability and minimal cable length.
- Deadband not behaving as expected:
  - Recalibrate deadbandMin/deadbandMax on the motor driver ECU.
  - Confirm bidirectional flag is set appropriately.

**Section sources**
- [src/ecu_joystick.cpp:167-170](file://src/ecu_joystick.cpp#L167-L170)
- [src/ecu_joystick.cpp:165-166](file://src/ecu_joystick.cpp#L165-L166)
- [src/ecu_motor_driver.cpp:101-135](file://src/ecu_motor_driver.cpp#L101-L135)

## Conclusion
The joystick ECU provides reliable analog and digital input handling for a dual-controller system. It leverages ESP32 ADC capabilities, efficient CAN messaging, and configurable deadband mapping on the motor driver side to deliver precise operator feedback. Proper calibration and attention to hardware connections ensure robust operation in field conditions.

[No sources needed since this section summarizes without analyzing specific files]

## Appendices

### Pin Assignments and Build Flags
- Joystick 1 environment defines POT1_PIN, POT2_PIN, BTN1_PIN, BTN2_PIN, and CAN pin assignments.
- Joystick 2 environment mirrors the same pins and logic for a second controller.

**Section sources**
- [platformio.ini:31-61](file://platformio.ini#L31-L61)
- [README.md:57-61](file://README.md#L57-L61)

### CAN ID Layout and PF Definitions
- J1939-like 29-bit ID with Priority, DP, PF, PS/DA, and SA.
- PF values for joystick: PF_JOYSTICK_POT1, PF_JOYSTICK_POT2, PF_JOYSTICK_BUTTONS.

**Section sources**
- [lib/ForwarderCAN/ForwarderCAN.h:22-34](file://lib/ForwarderCAN/ForwarderCAN.h#L22-L34)
- [lib/ForwarderCAN/ForwarderCAN.h:38-50](file://lib/ForwarderCAN/ForwarderCAN.h#L38-L50)

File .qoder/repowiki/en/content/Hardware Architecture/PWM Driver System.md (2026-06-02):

# PWM Driver System

<cite>
**Referenced Files in This Document**
- [README.md](file://README.md)
- [platformio.ini](file://platformio.ini)
- [main.cpp](file://src/main.cpp)
- [ecu_motor_driver.h](file://src/ecu_motor_driver.h)
- [ecu_motor_driver.cpp](file://src/ecu_motor_driver.cpp)
- [ForwarderConfig.h](file://lib/ForwarderConfig/ForwarderConfig.h)
- [ForwarderConfig.cpp](file://lib/ForwarderConfig/ForwarderConfig.cpp)
- [can_output.h](file://src/can_output.h)
- [can_output.cpp](file://src/can_output.cpp)
- [ota_webserver.cpp](file://src/ota_webserver.cpp)
</cite>

## Table of Contents
1. [Introduction](#introduction)
2. [Project Structure](#project-structure)
3. [Core Components](#core-components)
4. [Architecture Overview](#architecture-overview)
5. [Detailed Component Analysis](#detailed-component-analysis)
6. [Dependency Analysis](#dependency-analysis)
7. [Performance Considerations](#performance-considerations)
8. [Troubleshooting Guide](#troubleshooting-guide)
9. [Conclusion](#conclusion)
10. [Appendices](#appendices)

## Introduction
This document describes the PCA9685 PWM driver system used to control agricultural solenoids in an ESP32-based CAN ECU. It covers I2C communication setup, 8-channel MOSFET output configuration, PWM scaling from 0–255 to 12-bit resolution, solenoid actuation timing, safety timeout behavior, and practical wiring considerations. The system targets reliable, deterministic control of up to 16 solenoids via a dual PCA9685 configuration.

## Project Structure
The motor driver ECU is implemented as part of a larger CAN-based control system. The motor driver component initializes PCA9685 drivers, receives solenoid commands over CAN, applies mapping and deadband logic, and enforces a safety timeout to shut off outputs.

```mermaid
graph TB
MCU["ESP32-S3 MCU<br/>GPIO pins configured in build flags"]
I2C["I2C Bus<br/>SDA/SCL pins"]
PCA1["PCA9685 #1<br/>I2C 0x40"]
PCA2["PCA9685 #2<br/>I2C 0x41 (optional)"]
SOL["Solenoids x16<br/>8 per PCA9685"]
CAN["CAN Bus<br/>J1939-like framing"]
MCU --> I2C
I2C --> PCA1
I2C --> PCA2
PCA1 --> SOL
PCA2 --> SOL
MCU --> CAN
CAN --> MCU
```

**Diagram sources**
- [platformio.ini:26-29](file://platformio.ini#L26-L29)
- [ecu_motor_driver.cpp:39-41](file://src/ecu_motor_driver.cpp#L39-L41)
- [ecu_motor_driver.cpp:85-99](file://src/ecu_motor_driver.cpp#L85-L99)

**Section sources**
- [README.md:105-111](file://README.md#L105-L111)
- [platformio.ini:17-29](file://platformio.ini#L17-L29)
- [main.cpp:11-17](file://src/main.cpp#L11-L17)

## Core Components
- PCA9685 I2C PWM controllers: Two PCA9685 chips provide 16 channels of 12-bit PWM output for solenoid control.
- I2C configuration: SDA/SCL pins are defined via build flags and initialized at runtime.
- CAN protocol: Receives solenoid commands and broadcasts heartbeat/status.
- Deadband mapping: Joystick-to-solenoid mapping with configurable deadbands and PWM limits.
- Safety timeout: Automatically disables all solenoids after 500 ms of inactivity.

**Section sources**
- [ecu_motor_driver.cpp:39-41](file://src/ecu_motor_driver.cpp#L39-L41)
- [ecu_motor_driver.cpp:85-99](file://src/ecu_motor_driver.cpp#L85-L99)
- [ecu_motor_driver.cpp:101-135](file://src/ecu_motor_driver.cpp#L101-L135)
- [ecu_motor_driver.cpp:332-337](file://src/ecu_motor_driver.cpp#L332-L337)

## Architecture Overview
The motor driver runs on the ESP32 and controls solenoids through PCA9685 PWM outputs. It listens for CAN messages containing solenoid duty cycles (0–255), scales them to 12-bit values, and updates the appropriate PCA9685 channels. A watchdog timer ensures solenoids are turned off after 500 ms without a valid command.

```mermaid
sequenceDiagram
participant CAN as "CAN Bus"
participant ECU as "Motor Driver ECU"
participant PCA as "PCA9685 PWM Driver"
participant SOL as "Solenoids"
CAN->>ECU : "Solenoid Command (PF=0x21)"
ECU->>ECU : "Scale 0-255 to 0-4095"
ECU->>PCA : "setPWM(channel, value)"
PCA-->>SOL : "Apply PWM signal"
ECU->>ECU : "Reset lastSolenoidUpdate"
Note over ECU : "If no command within 500ms,<br/>ECU turns all solenoids OFF"
```

**Diagram sources**
- [ecu_motor_driver.cpp:206-218](file://src/ecu_motor_driver.cpp#L206-L218)
- [ecu_motor_driver.cpp:69-76](file://src/ecu_motor_driver.cpp#L69-L76)
- [ecu_motor_driver.cpp:332-337](file://src/ecu_motor_driver.cpp#L332-L337)

## Detailed Component Analysis

### I2C Communication Setup (ESP32 ↔ PCA9685)
- SDA/SCL pins are defined via build flags and applied at runtime.
- PCA9685 oscillator frequency is set to 25 MHz and PWM frequency to 200 Hz.
- The system probes for a second PCA9685 at address 0x41 and enables dual-PCA operation if present.

Key behaviors:
- Runtime pin assignment via Wire.setPins().
- Initialization sequence sets oscillator frequency and PWM frequency.
- Optional second PCA9685 detection and initialization.

**Section sources**
- [platformio.ini:26-29](file://platformio.ini#L26-L29)
- [ecu_motor_driver.cpp:85-99](file://src/ecu_motor_driver.cpp#L85-L99)

### 8-Channel MOSFET Output Configuration
- Each PCA9685 drives 8 channels; up to two PCA9685s provide 16 channels total.
- PWM resolution is 12 bits (0–4095), derived from 8-bit input scaling.
- Deadband mapping allows precise control around neutral positions for bidirectional operation.

Important constants and scaling:
- 12-bit PWM range: 0–4095.
- Input scaling: value_in_0_255 mapped to 0–4095.
- Deadband thresholds and PWM limits are stored per-axis.

**Section sources**
- [ecu_motor_driver.cpp:69-76](file://src/ecu_motor_driver.cpp#L69-L76)
- [ecu_motor_driver.cpp:101-135](file://src/ecu_motor_driver.cpp#L101-L135)
- [ForwarderConfig.h:41-57](file://lib/ForwarderConfig/ForwarderConfig.h#L41-L57)

### PWM Duty Cycle Scaling and Actuation Timing
- Input: 8-byte payload carrying 8 solenoid values (0–255).
- Scaling: Each byte is scaled to 12-bit using integer arithmetic.
- Update: setPWM(channel, value) writes the 12-bit value to the PCA9685 channel.
- Timing: PCA9685 PWM frequency is 200 Hz; switching occurs at this rate.

```mermaid
flowchart TD
Start(["Receive Solenoid Command"]) --> Scale["Scale 0-255 to 0-4095"]
Scale --> ChannelLoop{"For each channel"}
ChannelLoop --> |Write| SetPWM["setPWM(channel, value)"]
SetPWM --> UpdateWatchdog["Update lastSolenoidUpdate"]
UpdateWatchdog --> LoopEnd(["Loop Complete"])
```

**Diagram sources**
- [ecu_motor_driver.cpp:206-218](file://src/ecu_motor_driver.cpp#L206-L218)
- [ecu_motor_driver.cpp:69-76](file://src/ecu_motor_driver.cpp#L69-L76)

**Section sources**
- [ecu_motor_driver.cpp:206-218](file://src/ecu_motor_driver.cpp#L206-L218)
- [ecu_motor_driver.cpp:89-90](file://src/ecu_motor_driver.cpp#L89-L90)

### Safety Timeout Mechanism
- If no solenoid command is received within 500 ms, the system turns off all solenoids and resets the watchdog.
- The timeout is enforced in the main loop and only triggers after the first command has been processed.

Operational details:
- lastSolenoidUpdate tracks the last time a solenoid command was received.
- Timeout threshold is defined via build flag and used in the loop condition.

**Section sources**
- [platformio.ini:29](file://platformio.ini#L29)
- [ecu_motor_driver.cpp:332-337](file://src/ecu_motor_driver.cpp#L332-L337)
- [README.md:108](file://README.md#L108)

### CAN Protocol and Data Flow
- Solenoid commands are sent as a broadcast message with PF=0x21 and payload length ≥ 8.
- The payload carries 8 solenoid values; the driver scales and applies them to the first 8 channels.
- Heartbeat messages broadcast operational status periodically.

**Section sources**
- [README.md:40](file://README.md#L40)
- [ecu_motor_driver.cpp:206-218](file://src/ecu_motor_driver.cpp#L206-L218)
- [ecu_motor_driver.cpp:277-288](file://src/ecu_motor_driver.cpp#L277-L288)

### Deadband Mapping and Axis Configuration
- Each of up to 16 axes can map a joystick pot to a solenoid channel with configurable deadband and PWM limits.
- Bidirectional mode supports forward/reverse regions around a neutral zone.
- Configuration is persisted and transported over CAN in 8-byte records.

**Section sources**
- [ecu_motor_driver.cpp:101-135](file://src/ecu_motor_driver.cpp#L101-L135)
- [ForwarderConfig.h:41-57](file://lib/ForwarderConfig/ForwarderConfig.h#L41-L57)
- [ForwarderConfig.cpp:6-26](file://lib/ForwarderConfig/ForwarderConfig.cpp#L6-L26)

### Web Monitoring and Diagnostics
- The OTA web server exposes live solenoid values and joystick data for diagnostics.
- Live bars show current 12-bit PWM values per channel.

**Section sources**
- [ota_webserver.cpp:297-313](file://src/ota_webserver.cpp#L297-L313)
- [ota_webserver.cpp:540-546](file://src/ota_webserver.cpp#L540-L546)

## Dependency Analysis
The motor driver module depends on:
- Arduino Wire library for I2C communication.
- Adafruit_PWMServoDriver library for PCA9685 control.
- ForwarderCAN for CAN messaging.
- ForwarderConfig for persistent configuration storage.
- Optional OTA web server for remote diagnostics.

```mermaid
graph LR
ECU["ecu_motor_driver.cpp"]
Wire["Wire.h"]
PWM["Adafruit_PWMServoDriver.h"]
CAN["ForwarderCAN.h"]
CFG["ForwarderConfig.h"]
OTA["ota_webserver.h"]
OUT["can_output.h"]
ECU --> Wire
ECU --> PWM
ECU --> CAN
ECU --> CFG
ECU --> OTA
ECU --> OUT
```

**Diagram sources**
- [ecu_motor_driver.cpp:5-12](file://src/ecu_motor_driver.cpp#L5-L12)
- [platformio.ini:10-11](file://platformio.ini#L10-L11)

**Section sources**
- [ecu_motor_driver.cpp:5-12](file://src/ecu_motor_driver.cpp#L5-L12)
- [platformio.ini:10-11](file://platformio.ini#L10-L11)

## Performance Considerations
- PWM frequency: 200 Hz. This is suitable for solenoid applications where audible noise and switching losses are concerns.
- Resolution: 12-bit PWM provides fine granularity for proportional control.
- Deadband mapping reduces chatter near neutral positions.
- Watchdog timeout prevents unintended actuation after communication loss.

[No sources needed since this section provides general guidance]

## Troubleshooting Guide
Common issues and checks:
- PCA9685 not responding:
  - Verify SDA/SCL pin assignments in build flags.
  - Confirm PCA9685 addresses (0x40 and 0x41) and wiring continuity.
- No solenoid response:
  - Ensure CAN messages are received and PF=0x21.
  - Check watchdog timeout resetting outputs after 500 ms.
- Incorrect PWM scaling:
  - Confirm 0–255 input scaling to 0–4095.
  - Review deadband and PWM limits in configuration.

**Section sources**
- [platformio.ini:26-29](file://platformio.ini#L26-L29)
- [ecu_motor_driver.cpp:206-218](file://src/ecu_motor_driver.cpp#L206-L218)
- [ecu_motor_driver.cpp:332-337](file://src/ecu_motor_driver.cpp#L332-L337)

## Conclusion
The PCA9685-based PWM driver provides robust, scalable control for agricultural solenoids. With 12-bit resolution, configurable deadband mapping, and a 500 ms safety timeout, the system balances precision and safety. Proper I2C setup and attention to wiring and load characteristics ensure reliable operation.

[No sources needed since this section summarizes without analyzing specific files]

## Appendices

### Wiring and Safety Considerations
- I2C wiring:
  - SDA and SCL are connected to the PCA9685 per build flags.
  - Pull-up resistors are typically required on SDA/SCL lines.
- Solenoid wiring:
  - Each PCA9685 channel drives one solenoid through a MOSFET switch.
  - Flyback diode protection is essential across each solenoid coil to suppress inductive kickback.
- Power distribution:
  - Separate power supplies for logic (3.3 V) and solenoids are recommended.
  - Ensure adequate current capacity for all solenoids combined.
- Thermal management:
  - Continuous operation generates heat in the PCA9685 and MOSFETs.
  - Consider heatsinking or derating for sustained loads; monitor junction temperature.

[No sources needed since this section provides general guidance]

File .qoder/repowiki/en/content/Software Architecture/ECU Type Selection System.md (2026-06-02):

# ECU Type Selection System

<cite>
**Referenced Files in This Document**
- [main.cpp](file://src/main.cpp)
- [platformio.ini](file://platformio.ini)
- [README.md](file://README.md)
- [ecu_motor_driver.h](file://src/ecu_motor_driver.h)
- [ecu_motor_driver.cpp](file://src/ecu_motor_driver.cpp)
- [ecu_joystick.h](file://src/ecu_joystick.h)
- [ecu_joystick.cpp](file://src/ecu_joystick.cpp)
- [can_output.h](file://src/can_output.h)
- [can_output.cpp](file://src/can_output.cpp)
- [web_state.h](file://src/web_state.h)
- [ForwarderCAN.h](file://lib/ForwarderCAN/ForwarderCAN.h)
- [ForwarderCAN.cpp](file://lib/ForwarderCAN/ForwarderCAN.cpp)
- [ForwarderConfig.cpp](file://lib/ForwarderConfig/ForwarderConfig.cpp)
</cite>

## Table of Contents
1. [Introduction](#introduction)
2. [Project Structure](#project-structure)
3. [Core Components](#core-components)
4. [Architecture Overview](#architecture-overview)
5. [Detailed Component Analysis](#detailed-component-analysis)
6. [Dependency Analysis](#dependency-analysis)
7. [Performance Considerations](#performance-considerations)
8. [Troubleshooting Guide](#troubleshooting-guide)
9. [Conclusion](#conclusion)

## Introduction
This document explains ForwarderKE's ECU type selection mechanism using preprocessor directives and compile-time configuration. The system allows developers to choose between two distinct ECU implementations—motor driver and joystick—by defining specific build flags during compilation. This approach enables memory optimization, performance tuning, and clean separation of concerns through a shared interface pattern.

## Project Structure
The project is organized around a central entry point that conditionally includes the appropriate ECU implementation based on build flags. PlatformIO environments define the build flags and hardware pin assignments for each ECU type.

```mermaid
graph TB
A["src/main.cpp<br/>Entry Point"] --> B["Conditional Include<br/>ECU Type Selection"]
B --> C["src/ecu_motor_driver.h/.cpp<br/>Motor Driver Implementation"]
B --> D["src/ecu_joystick.h/.cpp<br/>Joystick Implementation"]
C --> E["lib/ForwarderCAN/*<br/>CAN/J1939 Protocol"]
D --> E
C --> F["lib/ForwarderConfig/*<br/>Persistent Configuration"]
D --> F
C --> G["src/can_output.h/.cpp<br/>CAN Output Rules"]
C --> H["src/web_state.h<br/>Shared State Defaults"]
D --> H
I["platformio.ini<br/>Build Environments"] --> A
I --> C
I --> D
```

**Diagram sources**
- [main.cpp:11-17](file://src/main.cpp#L11-L17)
- [platformio.ini:17-30](file://platformio.ini#L17-L30)
- [platformio.ini:31-61](file://platformio.ini#L31-L61)

**Section sources**
- [main.cpp:1-32](file://src/main.cpp#L1-L32)
- [platformio.ini:1-80](file://platformio.ini#L1-L80)

## Core Components
The ECU selection system centers on a small set of components that work together to provide a unified interface while enabling different implementations:

- **Entry Point**: The main application initializes serial communication and delegates to the selected ECU implementation via a common interface.
- **ECU Interface**: Both implementations expose identical function signatures (`ecu_setup()` and `ecu_loop()`) to ensure seamless switching.
- **Conditional Compilation**: Preprocessor directives select the appropriate ECU implementation at compile time.
- **Build Flags**: PlatformIO environments define the ECU type and hardware configuration through build flags.
- **Shared Libraries**: Both implementations rely on shared libraries for CAN protocol handling and persistent configuration.

Key characteristics:
- Compile-time selection eliminates runtime overhead and reduces binary size.
- The shared interface simplifies testing and deployment workflows.
- Hardware-specific configurations are isolated within each ECU implementation.

**Section sources**
- [main.cpp:19-31](file://src/main.cpp#L19-L31)
- [ecu_motor_driver.h:3-4](file://src/ecu_motor_driver.h#L3-L4)
- [ecu_joystick.h:3-4](file://src/ecu_joystick.h#L3-L4)

## Architecture Overview
The system uses a factory-like pattern where the build system selects the implementation at compile time. The main application remains unchanged regardless of the chosen ECU type.

```mermaid
sequenceDiagram
participant PIO as "PlatformIO Build System"
participant Main as "src/main.cpp"
participant Motor as "ecu_motor_driver.cpp"
participant Joy as "ecu_joystick.cpp"
participant CAN as "ForwarderCAN"
participant Config as "ForwarderConfig"
PIO->>Main : Define ECU_TYPE_MOTOR_DRIVER or ECU_TYPE_JOYSTICK
Main->>Main : Conditional include based on build flags
alt Motor Driver Selected
Main->>Motor : ecu_setup()
Motor->>CAN : Initialize CAN bus
Motor->>Config : Load configuration
Motor->>Motor : Initialize PCA9685 PWM drivers
Motor->>Motor : Configure LED and safety timers
Main->>Motor : ecu_loop()
Motor->>CAN : Process CAN messages
Motor->>CAN : Send heartbeat
Motor->>Motor : Update solenoids from joystick inputs
else Joystick Selected
Main->>Joy : ecu_setup()
Joy->>CAN : Initialize CAN bus
Joy->>Config : Load configuration
Joy->>Joy : Configure analog inputs and buttons
Joy->>Joy : Configure LED
Main->>Joy : ecu_loop()
Joy->>CAN : Read analog inputs
Joy->>CAN : Send joystick data
Joy->>CAN : Send heartbeat
end
```

**Diagram sources**
- [main.cpp:11-17](file://src/main.cpp#L11-L17)
- [ecu_motor_driver.cpp:290-325](file://src/ecu_motor_driver.cpp#L290-L325)
- [ecu_joystick.cpp:159-192](file://src/ecu_joystick.cpp#L159-L192)
- [ForwarderCAN.cpp:13-52](file://lib/ForwarderCAN/ForwarderCAN.cpp#L13-L52)
- [ForwarderConfig.cpp:56-69](file://lib/ForwarderConfig/ForwarderConfig.cpp#L56-L69)

## Detailed Component Analysis

### Build Flag System and Environment Configuration
PlatformIO environments define the ECU type and associated hardware configuration through build flags. Each environment sets the ECU type flag and provides device-specific pin assignments and operational parameters.

```mermaid
flowchart TD
Start(["Build Start"]) --> EnvSelect["Select PlatformIO Environment"]
EnvSelect --> MotorEnv{"motor_driver?"}
MotorEnv --> |Yes| SetMotorFlags["Define ECU_TYPE_MOTOR_DRIVER<br/>Set PCA9685 pins and address"]
MotorEnv --> |No| JoyEnv{"joystick1 or joystick2?"}
JoyEnv --> |Yes| SetJoyFlags["Define ECU_TYPE_JOYSTICK<br/>Set potentiometer and button pins"]
JoyEnv --> |No| Error["Error: Unknown environment"]
SetMotorFlags --> Compile["Compile with motor driver implementation"]
SetJoyFlags --> Compile
Compile --> End(["Binary Output"])
Error --> End
```

**Diagram sources**
- [platformio.ini:17-30](file://platformio.ini#L17-L30)
- [platformio.ini:31-61](file://platformio.ini#L31-L61)

**Section sources**
- [platformio.ini:17-30](file://platformio.ini#L17-L30)
- [platformio.ini:31-61](file://platformio.ini#L31-L61)

### Conditional Compilation in Main Application
The main application uses preprocessor directives to include the appropriate ECU implementation header. This creates a compile-time decision that determines which implementation is linked into the final binary.

```mermaid
flowchart TD
A["src/main.cpp"] --> B{"Defined ECU_TYPE_MOTOR_DRIVER?"}
B --> |Yes| C["Include ecu_motor_driver.h"]
B --> |No| D{"Defined ECU_TYPE_JOYSTICK?"}
D --> |Yes| E["Include ecu_joystick.h"]
D --> |No| F["Error: No ECU_TYPE defined"]
C --> G["Call ecu_setup() and ecu_loop()"]
E --> G
F --> H["Compilation fails"]
```

**Diagram sources**
- [main.cpp:11-17](file://src/main.cpp#L11-L17)

**Section sources**
- [main.cpp:11-17](file://src/main.cpp#L11-L17)

### Motor Driver ECU Implementation
The motor driver ECU controls solenoids via PCA9685 PWM drivers. It reads joystick inputs from the CAN bus and translates them into proportional solenoid commands.

Key features:
- Dual PCA9685 support with automatic detection
- Proportional mapping with deadband and PWM scaling
- Safety timeout to turn off solenoids after inactivity
- LED status indication with identification mode
- CAN output rules for GPIO control

```mermaid
classDiagram
class MotorDriverECU {
+ecu_setup()
+ecu_loop()
-initPCA()
-mapAxis(axis, potValue) uint16_t
-updateAxes()
-updateLED()
-processCAN()
-sendHeartbeat()
-setPWM(channel, value)
-allOff()
}
class ForwarderCAN {
+begin(txPin, rxPin, bitrate) bool
+loop()
+sendBroadcast(pf, data, len, priority)
+receive(msg, timeout) bool
+getAddress() uint8_t
+isOnline() bool
}
class ForwarderConfig {
+begin() bool
+getForcedAddress(defaultAddr) uint8_t
+loadMotorConfig(cfg)
+loadCanOutputRules(rules)
}
class Adafruit_PWMServoDriver {
+begin()
+setOscillatorFrequency(freq)
+setPWMFreq(freq)
+setPWM(channel, on, off)
}
class NeoPixelBus {
+Begin()
+SetPixelColor(index, color)
+Show()
}
MotorDriverECU --> ForwarderCAN : "uses"
MotorDriverECU --> ForwarderConfig : "uses"
MotorDriverECU --> Adafruit_PWMServoDriver : "controls PCA9685"
MotorDriverECU --> NeoPixelBus : "status LED"
```

**Diagram sources**
- [ecu_motor_driver.cpp:39-45](file://src/ecu_motor_driver.cpp#L39-L45)
- [ecu_motor_driver.cpp:290-325](file://src/ecu_motor_driver.cpp#L290-L325)
- [ForwarderCAN.h:66-72](file://lib/ForwarderCAN/ForwarderCAN.h#L66-L72)
- [ForwarderConfig.cpp:56-69](file://lib/ForwarderConfig/ForwarderConfig.cpp#L56-L69)

**Section sources**
- [ecu_motor_driver.cpp:39-99](file://src/ecu_motor_driver.cpp#L39-L99)
- [ecu_motor_driver.cpp:101-151](file://src/ecu_motor_driver.cpp#L101-L151)
- [ecu_motor_driver.cpp:184-275](file://src/ecu_motor_driver.cpp#L184-L275)
- [ecu_motor_driver.cpp:290-352](file://src/ecu_motor_driver.cpp#L290-L352)

### Joystick ECU Implementation
The joystick ECU reads analog inputs from potentiometers and button states, then publishes them over the CAN bus.

Key features:
- Analog input processing with configurable resolution and attenuation
- Button debouncing through threshold checking
- LED status indication with identification mode
- CAN address claiming and heartbeat broadcasting
- Optional CAN transceiver enable pin

```mermaid
classDiagram
class JoystickECU {
+ecu_setup()
+ecu_loop()
-readInputs()
-updateLED()
-sendPot(pf, value)
-sendButtons()
-processCAN()
-sendHeartbeat()
}
class ForwarderCAN {
+begin(txPin, rxPin, bitrate) bool
+loop()
+sendBroadcast(pf, data, len, priority)
+receive(msg, timeout) bool
+getAddress() uint8_t
+isOnline() bool
}
class ForwarderConfig {
+begin() bool
+getForcedAddress(defaultAddr) uint8_t
}
JoystickECU --> ForwarderCAN : "uses"
JoystickECU --> ForwarderConfig : "uses"
```

**Diagram sources**
- [ecu_joystick.cpp:39-41](file://src/ecu_joystick.cpp#L39-L41)
- [ecu_joystick.cpp:159-192](file://src/ecu_joystick.cpp#L159-L192)
- [ForwarderCAN.h:66-72](file://lib/ForwarderCAN/ForwarderCAN.h#L66-L72)
- [ForwarderConfig.cpp:56-69](file://lib/ForwarderConfig/ForwarderConfig.cpp#L56-L69)

**Section sources**
- [ecu_joystick.cpp:63-68](file://src/ecu_joystick.cpp#L63-L68)
- [ecu_joystick.cpp:106-112](file://src/ecu_joystick.cpp#L106-L112)
- [ecu_joystick.cpp:114-144](file://src/ecu_joystick.cpp#L114-L144)
- [ecu_joystick.cpp:159-236](file://src/ecu_joystick.cpp#L159-L236)

### CAN Output Rules System
The CAN output rules system provides a flexible mechanism to control GPIO pins based on incoming CAN messages. This feature is primarily used by the motor driver ECU to control external devices.

```mermaid
flowchart TD
A["CAN Message Received"] --> B["Match Rules"]
B --> C{"Rule Enabled?"}
C --> |No| D["Ignore"]
C --> |Yes| E{"PF Matches?"}
E --> |No| D
E --> |Yes| F{"SA Matches?"}
F --> |No| D
F --> |Yes| G{"Mode Toggle?"}
G --> |Yes| H["Toggle Output State"]
G --> |No| I["Set Output HIGH<br/>Start Momentary Timer"]
I --> J["Wait for Timeout<br/>Set Output LOW"]
```

**Diagram sources**
- [can_output.cpp:29-49](file://src/can_output.cpp#L29-L49)
- [can_output.cpp:51-61](file://src/can_output.cpp#L51-L61)

**Section sources**
- [can_output.h:7-9](file://src/can_output.h#L7-L9)
- [can_output.cpp:7-19](file://src/can_output.cpp#L7-L19)
- [can_output.cpp:29-61](file://src/can_output.cpp#L29-L61)

### Shared State Management
The web_state.h file provides default definitions for global variables that are only defined in the ECU implementation that is NOT being compiled in the current build. This prevents linker errors when switching between ECU types.

**Section sources**
- [web_state.h:6-19](file://src/web_state.h#L6-L19)

## Dependency Analysis
The ECU implementations share several dependencies while maintaining distinct hardware requirements.

```mermaid
graph TB
subgraph "Common Dependencies"
A["ForwarderCAN<br/>J1939 Protocol"]
B["ForwarderConfig<br/>Persistent Storage"]
C["NeoPixelBus<br/>LED Control"]
end
subgraph "Motor Driver Specific"
D["Adafruit_PWMServoDriver<br/>PCA9685 Control"]
E["can_output_rules<br/>GPIO Control"]
end
subgraph "Joystick Specific"
F["Analog Inputs<br/>Potentiometers"]
G["Digital Inputs<br/>Buttons"]
end
Main["src/main.cpp"] --> ECU["Selected ECU Implementation"]
ECU --> A
ECU --> B
ECU --> C
ECU --> D
ECU --> E
ECU --> F
ECU --> G
```

**Diagram sources**
- [ecu_motor_driver.cpp:5-12](file://src/ecu_motor_driver.cpp#L5-L12)
- [ecu_joystick.cpp:5-9](file://src/ecu_joystick.cpp#L5-L9)
- [ForwarderCAN.h:66-72](file://lib/ForwarderCAN/ForwarderCAN.h#L66-L72)
- [ForwarderConfig.cpp:56-69](file://lib/ForwarderConfig/ForwarderConfig.cpp#L56-L69)

**Section sources**
- [ecu_motor_driver.cpp:5-12](file://src/ecu_motor_driver.cpp#L5-L12)
- [ecu_joystick.cpp:5-9](file://src/ecu_joystick.cpp#L5-L9)

## Performance Considerations
Compile-time selection offers several performance and memory advantages:

- **Reduced Binary Size**: Only the selected ECU implementation and its dependencies are included, eliminating unused code paths.
- **Optimized Memory Usage**: Hardware-specific buffers and configurations are allocated only for the active implementation.
- **Eliminated Runtime Overhead**: The conditional inclusion decision happens at compile time, removing runtime branching costs.
- **Targeted Hardware Access**: Pin assignments and peripheral configurations are optimized for the specific ECU type.

Benefits for memory optimization and performance tuning:
- Motor driver builds exclude analog input processing and button handling code.
- Joystick builds exclude PCA9685 control and solenoid mapping logic.
- Build flags enable hardware-specific optimizations (e.g., CAN pin assignments, LED pin configuration).
- Safety timeouts and watchdog mechanisms are tailored to each implementation's requirements.

**Section sources**
- [platformio.ini:17-30](file://platformio.ini#L17-L30)
- [platformio.ini:31-61](file://platformio.ini#L31-L61)

## Troubleshooting Guide
Common issues and solutions when working with the ECU type selection system:

### Build Issues
- **Error: No ECU_TYPE defined**: Ensure you selected a valid PlatformIO environment (motor_driver, joystick1, or joystick2).
- **Missing hardware dependencies**: Verify that required libraries (Adafruit PWM Servo Driver, NeoPixelBus) are installed.
- **Pin conflicts**: Check that the selected pins in platformio.ini do not conflict with other peripherals.

### Runtime Issues
- **CAN initialization failures**: Verify CAN pin assignments and ensure the transceiver is properly connected.
- **PCA9685 detection problems**: Confirm I2C connections and address settings for the motor driver implementation.
- **Joystick input noise**: Adjust analog read resolution and attenuation settings in the joystick implementation.

### Debugging Tips
- Use the serial output to identify which ECU implementation is active and its initialization status.
- Monitor LED patterns for different operational states (normal, offline, identification).
- Utilize the heartbeat messages to verify CAN bus communication health.

**Section sources**
- [main.cpp:15-17](file://src/main.cpp#L15-L17)
- [ecu_motor_driver.cpp:305-316](file://src/ecu_motor_driver.cpp#L305-L316)
- [ecu_joystick.cpp:175-185](file://src/ecu_joystick.cpp#L175-L185)

## Conclusion
ForwarderKE's ECU type selection system demonstrates a clean and efficient approach to managing multiple device roles within a single codebase. Through strategic use of preprocessor directives and PlatformIO environments, the system achieves:

- **Clean Separation of Concerns**: Each ECU implementation maintains its own hardware-specific logic while sharing a common interface.
- **Memory Optimization**: Only the necessary code is compiled into each binary, reducing memory footprint and flash usage.
- **Development Flexibility**: Easy switching between implementations for testing and deployment scenarios.
- **Hardware Abstraction**: Shared libraries handle protocol details, allowing focus on device-specific functionality.

This architecture provides a solid foundation for extending the system with additional ECU types or integrating new hardware capabilities while maintaining code clarity and performance.

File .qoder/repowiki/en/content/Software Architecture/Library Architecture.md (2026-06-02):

# Library Architecture

<cite>
**Referenced Files in This Document**
- [README.md](file://README.md)
- [platformio.ini](file://platformio.ini)
- [ForwarderCAN.h](file://lib/ForwarderCAN/ForwarderCAN.h)
- [ForwarderCAN.cpp](file://lib/ForwarderCAN/ForwarderCAN.cpp)
- [ForwarderConfig.h](file://lib/ForwarderConfig/ForwarderConfig.h)
- [ForwarderConfig.cpp](file://lib/ForwarderConfig/ForwarderConfig.cpp)
- [main.cpp](file://src/main.cpp)
- [ecu_motor_driver.cpp](file://src/ecu_motor_driver.cpp)
- [ecu_joystick.cpp](file://src/ecu_joystick.cpp)
- [can_output.h](file://src/can_output.h)
- [web_state.h](file://src/web_state.h)
- [ota_webserver.h](file://src/ota_webserver.h)
</cite>

## Table of Contents
1. [Introduction](#introduction)
2. [Project Structure](#project-structure)
3. [Core Components](#core-components)
4. [Architecture Overview](#architecture-overview)
5. [Detailed Component Analysis](#detailed-component-analysis)
6. [Dependency Analysis](#dependency-analysis)
7. [Performance Considerations](#performance-considerations)
8. [Troubleshooting Guide](#troubleshooting-guide)
9. [Conclusion](#conclusion)

## Introduction
This document describes the shared library architecture of ForwarderKE, focusing on the separation of concerns between ForwarderCAN and ForwarderConfig. It explains how ForwarderCAN implements a J1939-like CAN protocol with address claiming and message handling, and how ForwarderConfig manages persistent storage using NVS (Non-Volatile Storage) and configuration. It also documents the library interfaces, dependency relationships, integration with ECU implementations, initialization sequences, global state management, and inter-library communication patterns.

## Project Structure
The project is organized around a small set of libraries and ECU-specific applications:
- lib/ForwarderCAN: Shared CAN/J1939 library providing address claiming, message framing, and transport.
- lib/ForwarderConfig: Shared configuration library providing NVS-backed persistence and configuration models.
- src: ECU implementations (motor driver and joysticks) plus shared utilities and web OTA components.

```mermaid
graph TB
subgraph "Libraries"
FCAN["ForwarderCAN<br/>J1939-like CAN transport"]
FCFG["ForwarderConfig<br/>NVS-backed config"]
end
subgraph "ECUs"
MD["Motor Driver ECU"]
JOY["Joystick ECU"]
end
subgraph "Utilities"
MAIN["Main Entrypoint"]
CO["CAN Output Rules Engine"]
WS["Web State"]
OTA["OTA Webserver"]
end
MAIN --> MD
MAIN --> JOY
MD --> FCAN
MD --> FCFG
MD --> CO
MD --> WS
MD --> OTA
JOY --> FCAN
JOY --> FCFG
JOY --> WS
JOY --> OTA
```

**Diagram sources**
- [main.cpp:19-31](file://src/main.cpp#L19-L31)
- [ecu_motor_driver.cpp:290-325](file://src/ecu_motor_driver.cpp#L290-L325)
- [ecu_joystick.cpp:159-191](file://src/ecu_joystick.cpp#L159-L191)
- [ForwarderCAN.h:66-119](file://lib/ForwarderCAN/ForwarderCAN.h#L66-L119)
- [ForwarderConfig.h:64-91](file://lib/ForwarderConfig/ForwarderConfig.h#L64-L91)

**Section sources**
- [README.md:112-126](file://README.md#L112-L126)
- [platformio.ini:1-80](file://platformio.ini#L1-L80)

## Core Components
- ForwarderCAN
  - Implements J1939-like 29-bit ID layout and PF/PS semantics.
  - Provides address claiming with arbitration and collision handling.
  - Encapsulates TWAI driver initialization, transmit/receive, and statistics.
  - Exposes send/receive APIs and address state queries.
- ForwarderConfig
  - Manages NVS namespace-scoped preferences.
  - Defines configuration models for axes, motor mapping, and CAN-triggered GPIO rules.
  - Provides load/save routines for persistent storage and defaults.

**Section sources**
- [ForwarderCAN.h:66-119](file://lib/ForwarderCAN/ForwarderCAN.h#L66-L119)
- [ForwarderCAN.cpp:13-52](file://lib/ForwarderCAN/ForwarderCAN.cpp#L13-L52)
- [ForwarderConfig.h:64-91](file://lib/ForwarderConfig/ForwarderConfig.h#L64-L91)
- [ForwarderConfig.cpp:56-59](file://lib/ForwarderConfig/ForwarderConfig.cpp#L56-L59)
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

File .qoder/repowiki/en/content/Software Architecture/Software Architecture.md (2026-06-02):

# Software Architecture

<cite>
**Referenced Files in This Document**
- [platformio.ini](file://platformio.ini)
- [README.md](file://README.md)
- [main.cpp](file://src/main.cpp)
- [ecu_motor_driver.cpp](file://src/ecu_motor_driver.cpp)
- [ecu_motor_driver.h](file://src/ecu_motor_driver.h)
- [ecu_joystick.cpp](file://src/ecu_joystick.cpp)
- [ecu_joystick.h](file://src/ecu_joystick.h)
- [can_output.cpp](file://src/can_output.cpp)
- [can_output.h](file://src/can_output.h)
- [ota_webserver.cpp](file://src/ota_webserver.cpp)
- [web_state.cpp](file://src/web_state.cpp)
- [ForwarderCAN.h](file://lib/ForwarderCAN/ForwarderCAN.h)
- [ForwarderConfig.h](file://lib/ForwarderConfig/ForwarderConfig.h)
</cite>

## Table of Contents
1. [Introduction](#introduction)
2. [Project Structure](#project-structure)
3. [Core Components](#core-components)
4. [Architecture Overview](#architecture-overview)
5. [Detailed Component Analysis](#detailed-component-analysis)
6. [Dependency Analysis](#dependency-analysis)
7. [Performance Considerations](#performance-considerations)
8. [Troubleshooting Guide](#troubleshooting-guide)
9. [Conclusion](#conclusion)
10. [Appendices](#appendices)
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

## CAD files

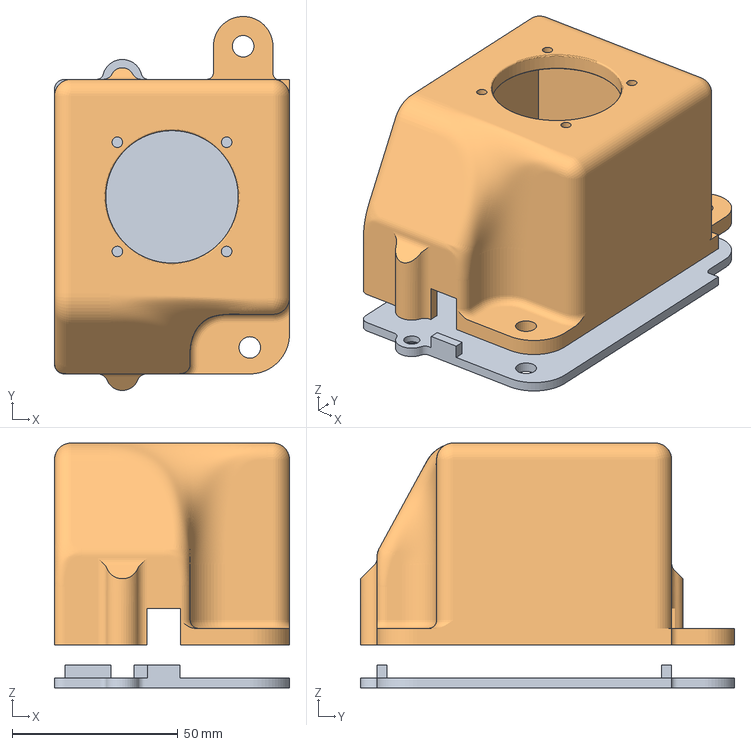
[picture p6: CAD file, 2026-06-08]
3D/joystick.3mf
71.0 x 113.0 x 74.0 mm
Lid
Top

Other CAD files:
3D/joystick.f3d

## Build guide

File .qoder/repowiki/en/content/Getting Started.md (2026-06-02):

# Getting Started

<cite>
**Referenced Files in This Document**
- [README.md](file://README.md)
- [platformio.ini](file://platformio.ini)
- [src/main.cpp](file://src/main.cpp)
- [src/ecu_motor_driver.cpp](file://src/ecu_motor_driver.cpp)
- [src/ecu_motor_driver.h](file://src/ecu_motor_driver.h)
- [src/ecu_joystick.cpp](file://src/ecu_joystick.cpp)
- [src/ecu_joystick.h](file://src/ecu_joystick.h)
- [src/can_output.h](file://src/can_output.h)
- [src/ota_webserver.h](file://src/ota_webserver.h)
- [lib/ForwarderCAN/ForwarderCAN.h](file://lib/ForwarderCAN/ForwarderCAN.h)
- [lib/ForwarderCAN/ForwarderCAN.cpp](file://lib/ForwarderCAN/ForwarderCAN.cpp)
- [lib/ForwarderConfig/ForwarderConfig.cpp](file://lib/ForwarderConfig/ForwarderConfig.cpp)
</cite>

## Table of Contents
1. [Introduction](#introduction)
2. [Prerequisites](#prerequisites)
3. [Hardware Assembly](#hardware-assembly)
4. [Build and Flash Procedures](#build-and-flash-procedures)
5. [Address Claiming Process](#address-claiming-process)
6. [Compile-time ECU Type Selection](#compile-time-ecu-type-selection)
7. [Wi-Fi Access Point and OTA Web Interface](#wi-fi-access-point-and-ota-web-interface)
8. [Safety Guidelines](#safety-guidelines)
9. [Verification and Initial Testing](#verification-and-initial-testing)
10. [Troubleshooting Guide](#troubleshooting-guide)
11. [Conclusion](#conclusion)

## Introduction
ForwarderKE is an ESP32-S3-based CAN bus controller designed to replace a factory controller in a forwarder (logging machine) hydraulic valve block. It implements a J1939-like addressing scheme over 250 kbps CAN and supports three ECUs on a single bus:
- Motor Driver ECU (controls 8 solenoids via PCA9685)
- Joystick 1 ECU (reads 3 pots + 2 buttons)
- Joystick 2 ECU (reads 3 pots + 2 buttons)

The system includes address claiming, heartbeat broadcasting, and optional Wi-Fi OTA updates with a web interface.

**Section sources**
- [README.md:1-131](file://README.md#L1-L131)

## Prerequisites
- Install PlatformIO (VS Code extension or CLI)
- ESP32-S3 development environment (Arduino framework)
- Basic familiarity with CAN bus and embedded development
- Optional: Wi-Fi access point for OTA updates

**Section sources**
- [README.md:63-91](file://README.md#L63-L91)
- [platformio.ini:1-80](file://platformio.ini#L1-L80)

## Hardware Assembly
Follow these steps to assemble the hardware for each ECU type:

- MCU: LilyGO T-CAN board (ESP32-S3 with built-in CAN transceiver)
- Motor driver PCB: PCA9685 I2C PWM controller with 8 MOSFET outputs
- Joysticks: 3 potentiometers + 2 buttons each

Pin assignments (defaults):
- CAN TX: GPIO 5
- CAN RX: GPIO 4
- Status LED (WS2812): GPIO 48
- I2C SDA: GPIO 21 (motor driver only)
- I2C SCL: GPIO 22 (motor driver only)
- Pot 1: GPIO 6 (joystick only)
- Pot 2: GPIO 7 (joystick only)
- Pot 3: GPIO 15 (joystick only)
- Button 1: GPIO 16 (joystick only)
- Button 2: GPIO 17 (joystick only)

Notes:
- Motor driver ECU requires PCA9685 I2C wiring to GPIO 21/22.
- Joystick ECUs require potentiometer and button wiring per the pin table above.
- Ensure power and ground connections are secure and isolated from high-current solenoid loads.

**Section sources**
- [README.md:48-62](file://README.md#L48-L62)
- [platformio.ini:17-62](file://platformio.ini#L17-L62)

## Build and Flash Procedures
Use PlatformIO environments to build and flash firmware for each ECU:

- Motor driver ECU:
  - Build: pio run -e motor_driver
  - Flash: pio run -e motor_driver --target upload
- Joystick 1 ECU:
  - Build: pio run -e joystick1
  - Flash: pio run -e joystick1 --target upload
- Joystick 2 ECU:
  - Build: pio run -e joystick2
  - Flash: pio run -e joystick2 --target upload

OTA builds include a Wi-Fi access point and web upload interface:
- Build and flash OTA: pio run -e motor_driver_ota --target upload
- After boot, connect to the AP named forwarder-motor (or forwarder-joy1 / forwarder-joy2), password: forwarder123
- Open http://192.168.4.1 or http://forwarder-motor.local
- Upload a .bin firmware file produced by pio run -e motor_driver

**Section sources**
- [README.md:63-103](file://README.md#L63-L103)
- [platformio.ini:17-80](file://platformio.ini#L17-L80)

## Address Claiming Process
On startup, each ECU attempts to claim its preferred address using J1939-style arbitration:
- The ECU sends an Address Claimed message containing its NAME.
- If another ECU claims the same address, arbitration proceeds by comparing NAME bytes.
- The lower NAME wins; the loser retries or tries an alternate address derived from the NAME hash.
- Once claimed, the ECU broadcasts a heartbeat every second and listens for commands.

```mermaid
sequenceDiagram
participant Boot as "ECU Boot"
participant CAN as "ForwarderCAN"
participant Bus as "CAN Bus"
participant Other as "Other ECU"
Boot->>CAN : "begin(tx, rx, bitrate)"
CAN->>Bus : "send Address Claimed (NAME)"
Bus-->>CAN : "other Address Claimed"
CAN->>CAN : "compare NAME"
alt "lower NAME"
CAN->>Bus : "re-send Address Claimed"
CAN-->>Boot : "address claimed"
else "higher NAME"
CAN->>CAN : "set state cannot_claim<br/>retry or alternate"
end
CAN-->>Boot : "online and ready"
```

**Diagram sources**
- [lib/ForwarderCAN/ForwarderCAN.cpp:13-52](file://lib/ForwarderCAN/ForwarderCAN.cpp#L13-L52)
- [lib/ForwarderCAN/ForwarderCAN.cpp:54-119](file://lib/ForwarderCAN/ForwarderCAN.cpp#L54-L119)
- [lib/ForwarderCAN/ForwarderCAN.cpp:121-142](file://lib/ForwarderCAN/ForwarderCAN.cpp#L121-L142)

**Section sources**
- [lib/ForwarderCAN/ForwarderCAN.cpp:13-119](file://lib/ForwarderCAN/ForwarderCAN.cpp#L13-L119)
- [lib/ForwarderCAN/ForwarderCAN.h:35-72](file://lib/ForwarderCAN/ForwarderCAN.h#L35-L72)
- [README.md:105-111](file://README.md#L105-L111)

## Compile-time ECU Type Selection
The ECU type is selected at compile time via build flags:
- ECU_TYPE_MOTOR_DRIVER: Builds the motor driver firmware with PCA9685 support and solenoid control.
- ECU_TYPE_JOYSTICK: Builds the joystick firmware with potentiometer and button inputs.
- ECU_JOYSTICK_ID: Distinguishes joystick units at compile time (joystick1 vs joystick2).
- ECU_PREFERRED_ADDRESS: Sets the preferred CAN address for each ECU type.

PlatformIO environments define these flags:
- motor_driver: defines ECU_TYPE_MOTOR_DRIVER and sets preferred address 0x20
- joystick1: defines ECU_TYPE_JOYSTICK, ECU_JOYSTICK_ID=1, preferred address 0x21
- joystick2: defines ECU_TYPE_JOYSTICK, ECU_JOYSTICK_ID=2, preferred address 0x22

```mermaid
flowchart TD
Start(["Build with PlatformIO"]) --> Env{"Select Environment"}
Env --> |motor_driver| FlagsMD["Define:<br/>ECU_TYPE_MOTOR_DRIVER<br/>ECU_PREFERRED_ADDRESS=0x20"]
Env --> |joystick1| FlagsJ1["Define:<br/>ECU_TYPE_JOYSTICK<br/>ECU_JOYSTICK_ID=1<br/>ECU_PREFERRED_ADDRESS=0x21"]
Env --> |joystick2| FlagsJ2["Define:<br/>ECU_TYPE_JOYSTICK<br/>ECU_JOYSTICK_ID=2<br/>ECU_PREFERRED_ADDRESS=0x22"]
FlagsMD --> Main["main.cpp includes ecu_motor_driver.h"]
FlagsJ1 --> MainJ["main.cpp includes ecu_joystick.h"]
FlagsJ2 --> MainJ
Main --> Build["Compile and Link"]
MainJ --> Build
Build --> Output["Flash via PlatformIO"]
```

**Diagram sources**
- [platformio.ini:17-62](file://platformio.ini#L17-L62)
- [src/main.cpp:11-17](file://src/main.cpp#L11-L17)

**Section sources**
- [README.md:43-46](file://README.md#L43-L46)
- [platformio.ini:17-62](file://platformio.ini#L17-L62)
- [src/main.cpp:11-17](file://src/main.cpp#L11-L17)

## Wi-Fi Access Point and OTA Web Interface
OTA-enabled builds include a Wi-Fi access point and a web server for uploading firmware binaries:
- Build OTA: pio run -e motor_driver_ota --target upload
- After boot:
  - Connect to the AP named forwarder-motor (or forwarder-joy1 / forwarder-joy2)
  - Password: forwarder123
  - Open http://192.168.4.1 or http://forwarder-motor.local
  - Upload a .bin firmware file generated by pio run -e motor_driver

OTA is enabled by adding -DENABLE_OTA_WEBSERVER to the build flags for the respective environment.

**Section sources**
- [README.md:84-103](file://README.md#L84-L103)
- [platformio.ini:63-80](file://platformio.ini#L63-L80)
- [src/ota_webserver.h:1-6](file://src/ota_webserver.h#L1-L6)

## Safety Guidelines
- Address claiming prevents address collisions on the bus.
- Solenoid timeout automatically turns off outputs after 500 ms without CAN commands.
- Bus-off recovery is handled automatically by the CAN driver.
- All ECUs broadcast a heartbeat every second to indicate health.

Additional best practices:
- Isolate high-current solenoid wiring from low-voltage control signals.
- Verify CAN termination and wiring integrity before powering high-current loads.
- Use appropriate fusing and circuit protection for solenoid circuits.

**Section sources**
- [README.md:105-111](file://README.md#L105-L111)
- [src/ecu_motor_driver.cpp:330-335](file://src/ecu_motor_driver.cpp#L330-L335)
- [lib/ForwarderCAN/ForwarderCAN.cpp:42-48](file://lib/ForwarderCAN/ForwarderCAN.cpp#L42-L48)

## Verification and Initial Testing
Successful setup verification steps:
- Observe onboard LED status:
  - Solid blue indicates normal operation.
  - Blinking red indicates CAN initialization failure.
  - Fast blinking yellow indicates recent joystick activity.
- Confirm address claiming:
  - Watch serial logs for “Address 0xXX claimed successfully”.
  - Verify heartbeat messages are being sent every second.
- Motor driver verification:
  - Send a solenoid command message to address 0x21 (from joystick 1) or 0x22 (from joystick 2).
  - Confirm solenoid outputs respond and PCA9685 channels update accordingly.
- Joystick verification:
  - Move joysticks and observe potentiometer and button messages appear on the bus.
  - Confirm LED color changes when sending an LED color message.
- OTA verification (optional):
  - Connect to the AP and upload a test binary.
  - Reboot and confirm the device boots into the new firmware.

Initial testing procedures:
- Power on all ECUs and observe LED patterns.
- Use a CAN analyzer or companion app to monitor heartbeat and joystick messages.
- For motor driver, apply known joystick inputs and verify solenoid response.
- If address conflicts occur, force a new address via a Set Address CAN message and save it to persistent storage.

**Section sources**
- [README.md:105-111](file://README.md#L105-L111)
- [src/ecu_motor_driver.cpp:290-323](file://src/ecu_motor_driver.cpp#L290-L323)
- [src/ecu_joystick.cpp:159-192](file://src/ecu_joystick.cpp#L159-L192)
- [lib/ForwarderCAN/ForwarderCAN.cpp:79-119](file://lib/ForwarderCAN/ForwarderCAN.cpp#L79-L119)

## Troubleshooting Guide
Common issues and resolutions:
- CAN initialization fails:
  - Symptoms: LED blinks red rapidly.
  - Actions: Check CAN wiring (TX/RX), verify correct pins, ensure 3.3V logic levels, and confirm bus termination.
- Address claiming fails or collides:
  - Symptoms: Repeated retries or alternate address assignment.
  - Actions: Verify unique ECU_NAME values across units; check preferred address flags; ensure only one unit attempts to claim an address at a time.
- No joystick or motor driver response:
  - Symptoms: No heartbeat or solenoid movement.
  - Actions: Confirm correct environment selection (joystick1 vs joystick2), verify potentiometer and button wiring, and check PCA9685 I2C connections for motor driver.
- OTA upload fails:
  - Symptoms: Cannot connect to AP or upload page not reachable.
  - Actions: Ensure OTA environment was built and flashed, verify AP SSID/password, and confirm the device is powered and booted.

**Section sources**
- [src/ecu_motor_driver.cpp:306-316](file://src/ecu_motor_driver.cpp#L306-L316)
- [src/ecu_joystick.cpp:175-185](file://src/ecu_joystick.cpp#L175-L185)
- [README.md:84-103](file://README.md#L84-L103)

## Conclusion
You are now equipped to set up ForwarderKE ECUs, configure hardware, build and flash firmware using PlatformIO, understand the address claiming process, and perform initial verification. For OTA updates, enable the OTA environments and use the built-in web interface. Adhere to safety guidelines when working with CAN bus and solenoid circuits, and consult the troubleshooting guide for common issues.

[No sources needed since this section summarizes without analyzing specific files]

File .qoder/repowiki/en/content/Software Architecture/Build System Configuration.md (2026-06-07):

# Build System Configuration

<cite>
**Referenced Files in This Document**
- [platformio.ini](file://platformio.ini)
- [.github/workflows/build.yml](file://.github/workflows/build.yml)
- [README.md](file://README.md)
- [src/main.cpp](file://src/main.cpp)
- [src/ecu_motor_driver.cpp](file://src/ecu_motor_driver.cpp)
- [src/ecu_motor_driver.h](file://src/ecu_motor_driver.h)
- [src/ecu_joystick.cpp](file://src/ecu_joystick.cpp)
- [src/ecu_joystick.h](file://src/ecu_joystick.h)
- [src/ota_webserver.cpp](file://src/ota_webserver.cpp)
- [src/ota_webserver.h](file://src/ota_webserver.h)
- [src/web_state.cpp](file://src/web_state.cpp)
- [src/web_state.h](file://src/web_state.h)
- [src/can_output.cpp](file://src/can_output.cpp)
- [lib/ForwarderCAN/ForwarderCAN.h](file://lib/ForwarderCAN/ForwarderCAN.h)
- [lib/ForwarderConfig/ForwarderConfig.h](file://lib/ForwarderConfig/ForwarderConfig.h)
- [build_flash.bat](file://build_flash.bat)
</cite>

## Update Summary
**Changes Made**
- Updated safety timeout from 80ms to 200ms across all environments for improved reliability
- Added soft_reset upload flags for ESP32-S3 boards to enhance OTA update reliability
- Enhanced upload speed configuration from 115200 to 460800 baud for ESP32-S3 UART-only environment
- Updated troubleshooting section to include upload speed and safety timeout considerations

## Table of Contents
1. [Introduction](#introduction)
2. [Project Structure](#project-structure)
3. [Core Components](#core-components)
4. [Architecture Overview](#architecture-overview)
5. [Detailed Component Analysis](#detailed-component-analysis)
6. [Dependency Analysis](#dependency-analysis)
7. [Performance Considerations](#performance-considerations)
8. [Troubleshooting Guide](#troubleshooting-guide)
9. [Conclusion](#conclusion)
10. [Appendices](#appendices)

## Introduction
This document explains the build system for ForwarderKE's PlatformIO configuration. It covers the eight distinct build environments, their purposes, and how they target different ECU types and deployment scenarios. The system now includes expanded ESP32-S3 support with USB-CDC enabled and UART-only variants, plus dual PCA9685 I2C addressing for enhanced hardware capabilities. It details compiler flags, build options, and ESP32-specific settings, describes the environment variable system for selecting ECU types, documents the release management process, and explains cross-compilation setup. Practical examples and troubleshooting guidance are included, along with CI/CD pipeline integration via GitHub Actions and automated release workflows.

## Project Structure
The project is organized around PlatformIO environments defined in the configuration file. Each environment compiles either the motor driver ECU or one of two joystick ECUs, with optional over-the-air (OTA) capabilities. The source tree separates ECU logic and shared libraries, while the CI workflow automates builds and releases across both legacy ESP32 and new ESP32-S3 targets.

```mermaid
graph TB
PIO["platformio.ini<br/>Environments & Flags"]
SRC_MAIN["src/main.cpp<br/>Entry point"]
ENV_MD_S3["env:motor_driver_s3<br/>ESP32-S3 + USB-CDC"]
ENV_MD_S3_UART["env:motor_driver_s3_uart<br/>ESP32-S3 + UART-only<br/>Upload Speed: 460800 baud<br/>Soft Reset: enabled"]
ENV_MD_LEG["env:motor_driver<br/>Legacy ESP32"]
ENV_J1["env:joystick1<br/>ESP32 + Joystick 1"]
ENV_J2["env:joystick2<br/>ESP32 + Joystick 2"]
ENV_MDO_S3["env:motor_driver_s3_ota<br/>extends motor_driver_s3 + OTA"]
ENV_MDO_S3_UART["env:motor_driver_s3_uart_ota<br/>extends motor_driver_s3_uart + OTA<br/>Soft Reset: enabled"]
ENV_MDO_LEG["env:motor_driver_ota<br/>extends motor_driver + OTA"]
ENV_J1O["env:joystick1_ota<br/>extends joystick1 + OTA"]
ENV_J2O["env:joystick2_ota<br/>extends joystick2 + OTA"]
LIB_CAN["lib/ForwarderCAN<br/>J1939-like CAN"]
LIB_CFG["lib/ForwarderConfig<br/>NVS-backed config"]
SRC_MAIN --> ENV_MD_S3
SRC_MAIN --> ENV_MD_S3_UART
SRC_MAIN --> ENV_MD_LEG
SRC_MAIN --> ENV_J1
SRC_MAIN --> ENV_J2
ENV_MDO_S3 --> SRC_MAIN
ENV_MDO_S3_UART --> SRC_MAIN
ENV_MDO_LEG --> SRC_MAIN
ENV_J1O --> SRC_MAIN
ENV_J2O --> SRC_MAIN
ENV_MD_S3 --> SRC_MD["src/ecu_motor_driver.cpp/.h"]
ENV_MD_S3_UART --> SRC_MD
ENV_MD_LEG --> SRC_MD
ENV_J1 --> SRC_J1["src/ecu_joystick.cpp/.h"]
ENV_J2 --> SRC_J2["src/ecu_joystick.cpp/.h"]
SRC_MD --> LIB_CAN
SRC_MD --> LIB_CFG
SRC_J1 --> LIB_CAN
SRC_J2 --> LIB_CAN
CI["GitHub Actions<br/>.github/workflows/build.yml"]
CI --> ENV_MD_S3
CI --> ENV_MD_S3_UART
CI --> ENV_MD_LEG
CI --> ENV_J1
CI --> ENV_J2
CI --> ENV_MDO_S3
CI --> ENV_MDO_S3_UART
CI --> ENV_MDO_LEG
CI --> ENV_J1O
CI --> ENV_J2O
```

**Diagram sources**
- [platformio.ini:1-148](file://platformio.ini#L1-L148)
- [src/main.cpp:1-39](file://src/main.cpp#L1-L39)
- [src/ecu_motor_driver.cpp:1-479](file://src/ecu_motor_driver.cpp#L1-L479)
- [src/ecu_joystick.cpp:1-239](file://src/ecu_joystick.cpp#L1-L239)
- [.github/workflows/build.yml:1-81](file://.github/workflows/build.yml#L1-L81)
- [lib/ForwarderCAN/ForwarderCAN.h:1-137](file://lib/ForwarderCAN/ForwarderCAN.h#L1-L137)
- [lib/ForwarderConfig/ForwarderConfig.h:1-100](file://lib/ForwarderConfig/ForwarderConfig.h#L1-L100)

**Section sources**
- [platformio.ini:1-148](file://platformio.ini#L1-L148)
- [README.md:1-194](file://README.md#L1-L194)

## Core Components
- PlatformIO configuration defines a base environment and eight environments: three ESP32-S3 variants (USB-CDC enabled, UART-only, and legacy), two joystick environments, plus four OTA variants extending the base environments.
- The entry point selects the ECU implementation at compile time via build flags.
- ECU-specific implementations configure hardware pins, CAN bitrates, and device-specific peripherals.
- Shared libraries encapsulate CAN protocol handling and persistent configuration.
- GitHub Actions automates builds for all environments and creates releases from tagged commits.

**Section sources**
- [platformio.ini:1-148](file://platformio.ini#L1-L148)
- [src/main.cpp:1-39](file://src/main.cpp#L1-L39)
- [lib/ForwarderCAN/ForwarderCAN.h:1-137](file://lib/ForwarderCAN/ForwarderCAN.h#L1-L137)
- [lib/ForwarderConfig/ForwarderConfig.h:1-100](file://lib/ForwarderConfig/ForwarderConfig.h#L1-L100)
- [.github/workflows/build.yml:1-81](file://.github/workflows/build.yml#L1-L81)

## Architecture Overview
The build system centers on PlatformIO environments that inject compile-time flags to choose the ECU type and board-specific pin assignments. The entry point conditionally includes the appropriate ECU module. OTA-enabled environments add a Wi-Fi AP and web server for firmware updates. The CI pipeline builds all environments and, on tag pushes, packages firmware binaries into a GitHub Release. The new ESP32-S3 variants offer enhanced USB-CDC support and flexible UART configurations for different deployment scenarios, with optimized upload speeds for improved development workflow and enhanced OTA reliability through soft reset uploads.

```mermaid
sequenceDiagram
participant Dev as "Developer"
participant PIO as "PlatformIO CLI"
participant Env as "Environment Config"
participant Src as "Source Files"
participant Lib as "Libraries"
participant FW as "Firmware.bin"
Dev->>PIO : pio run -e <env>
PIO->>Env : Load platform/board/framework/build_flags
Env-->>PIO : Merge inherited flags (extends)
PIO->>Src : Compile with selected ECU flags
Src->>Lib : Link ForwarderCAN, ForwarderConfig
Lib-->>Src : Symbols resolved
Src-->>FW : Produce firmware.bin
Dev-->>FW : Upload via serial (460800 baud for UART-only with soft reset)
```

**Diagram sources**
- [platformio.ini:1-148](file://platformio.ini#L1-L148)
- [src/main.cpp:1-39](file://src/main.cpp#L1-L39)
- [src/ecu_motor_driver.cpp:1-479](file://src/ecu_motor_driver.cpp#L1-L479)
- [src/ecu_joystick.cpp:1-239](file://src/ecu_joystick.cpp#L1-L239)
- [lib/ForwarderCAN/ForwarderCAN.h:1-137](file://lib/ForwarderCAN/ForwarderCAN.h#L1-L137)
- [lib/ForwarderConfig/ForwarderConfig.h:1-100](file://lib/ForwarderConfig/ForwarderConfig.h#L1-L100)

## Detailed Component Analysis

### Build Environments and Purposes
- Base environment settings:
  - Platform: ESP32 Arduino framework
  - Board: ESP32-S3 DevKit C-1 by default
  - Monitor speed: 115200
  - Global libraries: Adafruit PWM Servo Driver, NeoPixelBus
  - Global build flags: CAN bitrate, protocol priority, watchdog timeout
- **ESP32-S3 USB-CDC Enabled** (`motor_driver_s3`):
  - Selects motor driver ECU with USB-CDC support
  - Uses ESP32-S3 Box board with 8MB flash partition
  - Enables `ARDUINO_USB_CDC_ON_BOOT=1` for USB serial support
  - CAN TX/RX pins, onboard WS2812 LED pin, dual PCA9685 I2C pins and addresses
  - Safety timeout for solenoid outputs increased to 200ms for improved reliability
- **ESP32-S3 UART-Only** (`motor_driver_s3_uart`):
  - Selects motor driver ECU without USB-CDC
  - Uses standard ESP32-S3 DevKit C-1 board
  - Same pin assignments as S3 variant but without USB-CDC
  - Upload speed set to 460800 baud for significantly faster serial flashing
  - Soft reset upload flags enabled for enhanced OTA reliability
- **Legacy ESP32** (`motor_driver`):
  - Traditional motor driver ECU for T-CAN boards
  - Uses ESP32 DevKit with legacy pin assignments
  - CAN TX/RX pins, onboard WS2812 LED pin, dual PCA9685 I2C pins and addresses
  - Safety timeout for solenoid outputs increased to 200ms for improved reliability
- **Joystick Environments** (`joystick1`, `joystick2`):
  - Selects joystick ECU with 3 pots and 2 buttons
  - Preferred address and joystick ID constants
  - CAN TX/RX/SE pins, onboard WS2812 LED pin
  - Potentiometer and button pins
  - Safety timeout for solenoid outputs increased to 200ms for improved reliability
- **OTA Variants**:
  - Extend their respective base environments
  - Add a flag enabling the embedded OTA web server
  - Soft reset upload flags enabled for ESP32-S3 variants

Practical usage examples:
- Build ESP32-S3 USB-CDC motor driver: `pio run -e motor_driver_s3`
- Build ESP32-S3 UART-only motor driver: `pio run -e motor_driver_s3_uart`
- Build legacy ESP32 motor driver: `pio run -e motor_driver`
- Build joystick 1: `pio run -e joystick1`
- Build joystick 2: `pio run -e joystick2`
- Build OTA motor driver (S3): `pio run -e motor_driver_s3_ota`

**Updated** Increased safety timeout from 80ms to 200ms across all environments for improved reliability, added soft_reset upload flags for ESP32-S3 boards to enhance OTA update reliability

**Section sources**
- [platformio.ini:17-148](file://platformio.ini#L17-L148)
- [README.md:126-145](file://README.md#L126-L145)

### Environment Variable System for ECU Type Selection
- The entry point uses preprocessor directives to include the correct ECU module based on a single build flag:
  - `ECU_TYPE_MOTOR_DRIVER` selects the motor driver implementation
  - `ECU_TYPE_JOYSTICK` selects the joystick implementation
- If neither flag is defined, compilation fails with an explicit error, ensuring intentional ECU selection.
- **USB-CDC Support**: The main entry point checks for `ARDUINO_USB_CDC_ON_BOOT` to handle USB enumeration timing for ESP32-S3 boards.

```mermaid
flowchart TD
Start(["Compile with build flags"]) --> CheckCDC{"ARDUINO_USB_CDC_ON_BOOT defined?"}
CheckCDC --> |Yes| WaitUSB["Wait for USB-CDC enumeration"]
CheckCDC --> |No| CheckMD{"ECU_TYPE_MOTOR_DRIVER defined?"}
WaitUSB --> CheckMD
CheckMD --> |Yes| IncludeMD["Include ecu_motor_driver.h"]
CheckMD --> |No| CheckJoy{"ECU_TYPE_JOYSTICK defined?"}
CheckJoy --> |Yes| IncludeJoy["Include ecu_joystick.h"]
CheckJoy --> |No| Error["Compilation error: no ECU_TYPE defined"]
IncludeMD --> Build["Proceed with motor driver build"]
IncludeJoy --> Build
Error --> End(["Stop"])
Build --> End
```

**Diagram sources**
- [src/main.cpp:21-27](file://src/main.cpp#L21-L27)

**Section sources**
- [src/main.cpp:6-17](file://src/main.cpp#L6-L17)
- [src/main.cpp:21-27](file://src/main.cpp#L21-L27)

### Compiler Flags, Build Options, and ESP32 Settings
- Global flags:
  - `CAN_BITRATE`: sets the CAN bus bitrate
  - `PROTOCOL_PRIORITY_DEFAULT`: default priority for outgoing CAN frames
  - `WATCHDOG_TIMEOUT_MS`: global watchdog timeout
- **ESP32-S3 USB-CDC Variant** (`motor_driver_s3`):
  - `ECU_TYPE_MOTOR_DRIVER`, `ECU_PREFERRED_ADDRESS=0x20`, `ECU_NAME_MOTOR_DRIVER=0x01`
  - `ARDUINO_USB_CDC_ON_BOOT=1`: enables USB serial support
  - `CONFIG_I2CDEV_NOLOCK=1`: disables I2C locking for performance
  - CAN TX/RX pins, WS2812 pin, dual PCA9685 I2C addresses (0x40, 0x41)
  - Safety timeout for solenoid outputs increased to 200ms for improved reliability
- **ESP32-S3 UART-Only Variant** (`motor_driver_s3_uart`):
  - Same as S3 variant but without USB-CDC support
  - Upload speed set to 460800 baud for significantly faster serial flashing
  - Soft reset upload flags enabled for enhanced OTA reliability
  - Safety timeout for solenoid outputs increased to 200ms for improved reliability
- **Legacy ESP32 Variant** (`motor_driver`):
  - Traditional pin assignments for T-CAN boards
  - CAN TX/RX pins, onboard WS2812 LED pin, dual PCA9685 I2C pins and addresses
  - Safety timeout for solenoid outputs increased to 200ms for improved reliability
- **Joystick Environments** (`joystick1`, `joystick2`):
  - `ECU_TYPE_JOYSTICK`, `ECU_PREFERRED_ADDRESS=0x21/0x22`, `ECU_JOYSTICK_ID=1/2`
  - CAN TX/RX/SE pins, onboard WS2812 LED pin
  - Potentiometer and button pins
  - Safety timeout for solenoid outputs increased to 200ms for improved reliability
- **OTA Environments**:
  - `ENABLE_OTA_WEBSERVER` flag enables the embedded web server and AP
  - Soft reset upload flags enabled for ESP32-S3 variants

Board and framework:
- Platform: espressif32
- Framework: arduino
- **Default board**: esp32-s3-devkitc-1 (base environment)
- **ESP32-S3 USB-CDC board**: esp32s3box with 8MB flash partition
- **ESP32-S3 UART-only board**: esp32-s3-devkitc-1
- **Legacy board**: esp32dev
- Per-environment overrides:
  - ESP32-S3 variants override board to specific models
  - Joystick environments override board to esp32dev

**Updated** Increased safety timeout from 80ms to 200ms across all environments for improved reliability, added soft_reset upload flags for ESP32-S3 boards to enhance OTA update reliability

**Section sources**
- [platformio.ini:4-148](file://platformio.ini#L4-L148)

### ECU-Specific Implementations

#### Motor Driver ECU
- Initializes dual PCA9685 PWM drivers (one or two units), onboard LED, CAN controller, and persistent configuration
- Receives joystick inputs and solenoid commands over CAN, maps joystick values to solenoid outputs, and enforces safety timeouts
- Supports OTA via embedded web server when enabled
- **Dual PCA9685 Support**: Automatically detects and configures second PCA9685 controller for expanded 16-channel PWM output
- **Safety Timeout**: All motor driver variants now enforce a 200ms safety timeout for solenoid outputs to prevent stale actuator states

```mermaid
classDiagram
class ForwarderCAN {
+begin(txPin, rxPin, bitrate) bool
+loop() void
+sendBroadcast(pf, data, len, priority) bool
+receive(msg, timeoutMs) bool
+isOnline() bool
+getAddress() uint8
}
class ForwarderConfig {
+begin() bool
+getForcedAddress(defaultAddr) uint8
+setForcedAddress(addr) void
+loadMotorConfig(cfg) bool
+saveMotorConfig(cfg) bool
+saveAxisConfig(axisIdx, axis) bool
+loadCanOutputRules(rules) bool
+saveCanOutputRule(index, rule) bool
}
class MotorDriver {
+ecu_setup() void
+ecu_loop() void
-initPCA() void
+mapAxis(axis, potValue) uint16
+processCAN() void
+updateAxes() void
+updateLED() void
+sendHeartbeat() void
}
class DualPCA9685 {
+detectPCA9685() bool
+setPWM(channel, value) void
+begin() void
}
MotorDriver --> ForwarderCAN : "uses"
MotorDriver --> ForwarderConfig : "uses"
MotorDriver --> DualPCA9685 : "uses"
DualPCA9685 --> PCA9685_I2C_ADDR1 : "0x40"
DualPCA9685 --> PCA9685_I2C_ADDR2 : "0x41"
```

**Diagram sources**
- [src/ecu_motor_driver.cpp:39-99](file://src/ecu_motor_driver.cpp#L39-L99)
- [lib/ForwarderCAN/ForwarderCAN.h:1-137](file://lib/ForwarderCAN/ForwarderCAN.h#L1-L137)
- [lib/ForwarderConfig/ForwarderConfig.h:1-100](file://lib/ForwarderConfig/ForwarderConfig.h#L1-L100)

**Section sources**
- [src/ecu_motor_driver.cpp:1-479](file://src/ecu_motor_driver.cpp#L1-L479)
- [src/ecu_motor_driver.h:1-5](file://src/ecu_motor_driver.h#L1-L5)

#### Joystick ECU
- Reads three potentiometers and two buttons, periodically broadcasting joystick data and button states over CAN
- Supports OTA via embedded web server when enabled
- **Safety Timeout**: All joystick variants now enforce a 200ms safety timeout for solenoid outputs to prevent stale actuator states

```mermaid
classDiagram
class ForwarderCAN {
+begin(txPin, rxPin, bitrate) bool
+loop() void
+sendBroadcast(pf, data, len, priority) bool
+receive(msg, timeoutMs) bool
+isOnline() bool
+getAddress() uint8
}
class ForwarderConfig {
+begin() bool
+getForcedAddress(defaultAddr) uint8
+setForcedAddress(addr) void
}
class Joystick {
+ecu_setup() void
+ecu_loop() void
-readInputs() void
+updateLED() void
+processCAN() void
+sendPot(pf, value) void
+sendButtons() void
+sendHeartbeat() void
}
Joystick --> ForwarderCAN : "uses"
Joystick --> ForwarderConfig : "uses"
```

**Diagram sources**
- [src/ecu_joystick.cpp:1-239](file://src/ecu_joystick.cpp#L1-L239)
- [lib/ForwarderCAN/ForwarderCAN.h:1-137](file://lib/ForwarderCAN/ForwarderCAN.h#L1-L137)
- [lib/ForwarderConfig/ForwarderConfig.h:1-100](file://lib/ForwarderConfig/ForwarderConfig.h#L1-L100)

**Section sources**
- [src/ecu_joystick.cpp:1-239](file://src/ecu_joystick.cpp#L1-L239)
- [src/ecu_joystick.h:1-5](file://src/ecu_joystick.h#L1-L5)

### OTA Web Server
- Enabled by the `ENABLE_OTA_WEBSERVER` flag
- Creates a Wi-Fi AP with a predictable hostname and serves a dashboard UI
- Provides endpoints to:
  - View live state and bus statistics
  - Configure joystick-to-solenoid mapping
  - Configure CAN-triggered GPIO outputs
  - Perform firmware updates via HTTP POST
- Uses mDNS for service discovery
- **Enhanced Reliability**: ESP32-S3 variants now use soft reset upload flags to improve OTA update reliability

```mermaid
sequenceDiagram
participant Host as "Host Device"
participant AP as "ESP32 AP"
participant UI as "Web UI"
participant OTA as "OTA Handler"
Host->>AP : Connect to AP (SSID : forwarder-*)
Host->>UI : Open http : //192.168.4.1 or http : //<hostname>.local
UI->>OTA : POST /update with .bin file
OTA->>OTA : Update.begin(write,end) with soft reset
OTA-->>UI : 200 OK
UI-->>Host : "Update successful! Rebooting..."
AP-->>Host : AP disconnects after reboot
```

**Diagram sources**
- [src/ota_webserver.cpp:766-796](file://src/ota_webserver.cpp#L766-L796)
- [platformio.ini:40-43](file://platformio.ini#L40-L43)

**Section sources**
- [src/ota_webserver.cpp:1-809](file://src/ota_webserver.cpp#L1-L809)
- [src/ota_webserver.h:1-6](file://src/ota_webserver.h#L1-L6)
- [README.md:147-166](file://README.md#L147-L166)

### Cross-Compilation and Dependency Resolution
- Platform: ESP32 (Espressif)
- Framework: Arduino
- **Board selection per environment**:
  - **Base**: esp32-s3-devkitc-1
  - **ESP32-S3 USB-CDC**: esp32s3box with 8MB flash partition
  - **ESP32-S3 UART-only**: esp32-s3-devkitc-1 with 460800 baud upload speed and soft reset flags
  - **Legacy**: esp32dev
- Libraries:
  - Adafruit PWM Servo Driver Library
  - Makuna NeoPixelBus
- Shared libraries:
  - ForwarderCAN: J1939-like 29-bit ID layout, PF definitions, address claiming, send/receive helpers
  - ForwarderConfig: NVS-backed configuration for axes and CAN output rules

**Updated** Increased safety timeout from 80ms to 200ms across all environments for improved reliability, added soft_reset upload flags for ESP32-S3 boards to enhance OTA update reliability

**Section sources**
- [platformio.ini:4-148](file://platformio.ini#L4-L148)
- [lib/ForwarderCAN/ForwarderCAN.h:1-137](file://lib/ForwarderCAN/ForwarderCAN.h#L1-L137)
- [lib/ForwarderConfig/ForwarderConfig.h:1-100](file://lib/ForwarderConfig/ForwarderConfig.h#L1-L100)

### CI/CD Pipeline Integration
- Triggers on pushes to main and tags matching v*
- **Matrix builds all eight environments** (including new ESP32-S3 variants)
- Caches PlatformIO installation to speed up jobs
- Installs PlatformIO Core and builds each environment
- Uploads firmware artifacts for later use
- On tag pushes, downloads all firmware artifacts, renames them to environment-specific filenames, and creates a GitHub Release with prerelease detection

```mermaid
sequenceDiagram
participant GH as "Git Push/PR"
participant ACT as "GitHub Actions"
participant PIO as "PlatformIO"
participant ART as "Artifacts"
participant REL as "GitHub Release"
GH->>ACT : on push/pull_request
ACT->>PIO : pio run -e <env> (matrix with 8 environments)
PIO-->>ART : .pio/build/<env>/firmware.bin
ACT->>REL : on tags, create release
REL-->>GH : publish release assets
```

**Diagram sources**
- [.github/workflows/build.yml:1-81](file://.github/workflows/build.yml#L1-L81)

**Section sources**
- [.github/workflows/build.yml:1-81](file://.github/workflows/build.yml#L1-L81)

## Dependency Analysis
The build-time selection and environment flags create a tight coupling between configuration and source modules. The shared state and web UI rely on conditional compilation to expose only relevant symbols. The new ESP32-S3 variants introduce additional complexity with USB-CDC support and dual PCA9685 detection.

```mermaid
graph LR
Flags["Build Flags<br/>ECU_TYPE_*, USB-CDC, PCA9685, SAFETY_TIMEOUT"] --> Main["src/main.cpp"]
Main --> MD["src/ecu_motor_driver.cpp"]
Main --> J1["src/ecu_joystick.cpp"]
MD --> CAN["lib/ForwarderCAN"]
MD --> CFG["lib/ForwarderConfig"]
J1 --> CAN
OWA["src/ota_webserver.cpp"] --> MD
OWA --> J1
WEB["src/web_state.cpp"] --> MD
WEB --> J1
S3_Board["ESP32-S3 Boards<br/>USB-CDC, UART-only, Soft Reset"] --> MD
Legacy_Board["Legacy ESP32 Boards"] --> MD
Legacy_Board --> J1
```

**Diagram sources**
- [src/main.cpp:6-17](file://src/main.cpp#L6-L17)
- [src/ecu_motor_driver.cpp:1-479](file://src/ecu_motor_driver.cpp#L1-L479)
- [src/ecu_joystick.cpp:1-239](file://src/ecu_joystick.cpp#L1-L239)
- [src/ota_webserver.cpp:1-809](file://src/ota_webserver.cpp#L1-L809)
- [src/web_state.cpp:1-20](file://src/web_state.cpp#L1-L20)
- [lib/ForwarderCAN/ForwarderCAN.h:1-137](file://lib/ForwarderCAN/ForwarderCAN.h#L1-L137)
- [lib/ForwarderConfig/ForwarderConfig.h:1-100](file://lib/ForwarderConfig/ForwarderConfig.h#L1-L100)

**Section sources**
- [src/main.cpp:6-17](file://src/main.cpp#L6-L17)
- [src/web_state.cpp:1-20](file://src/web_state.cpp#L1-L20)

## Performance Considerations
- CAN bitrate and priority defaults balance responsiveness and bus efficiency.
- **Enhanced Safety Timeout**: All environments now use a 200ms safety timeout for solenoid outputs, improving system reliability and preventing stale actuator states.
- Watchdog and safety timeouts prevent stale actuator states.
- OTA update progress reporting and mDNS availability improve operational reliability.
- Using cached PlatformIO installations reduces CI runtime overhead.
- **ESP32-S3 USB-CDC**: Provides faster development workflow with USB serial support.
- **Dual PCA9685**: Enables 16-channel PWM output for expanded hardware capabilities.
- **I2C Locking Disabled**: Improves I2C performance for multiple PCA9685 controllers.
- **Enhanced Upload Speed**: ESP32-S3 UART-only environment now uses 460800 baud upload speed, significantly reducing firmware flashing times during development compared to the previous 115200 baud rate.
- **Soft Reset Uploads**: ESP32-S3 variants use soft reset upload flags to improve OTA update reliability and reduce upload failures.

## Troubleshooting Guide
Common build issues and resolutions:
- Missing ECU type flag:
  - Symptom: Compilation error indicating no ECU_TYPE defined
  - Fix: Choose one of the eight environments (e.g., motor_driver_s3, motor_driver_s3_uart, motor_driver, joystick1, joystick2, or their OTA variants)
- **ESP32-S3 USB-CDC Issues**:
  - Symptom: USB serial not available or slow enumeration
  - Fix: Ensure `ARDUINO_USB_CDC_ON_BOOT=1` is defined for S3 variants; verify ESP32-S3 board configuration
- **Dual PCA9685 Detection Failures**:
  - Symptom: Only 8 channels available instead of expected 16
  - Fix: Verify PCA9685 I2C addresses (0x40, 0x41) are correct and both controllers are physically connected
- **UART-Only vs USB-CDC Confusion**:
  - Symptom: Unexpected serial communication behavior
  - Fix: Choose appropriate environment - motor_driver_s3 for USB-CDC, motor_driver_s3_uart for pure UART
- **Upload Speed Issues**:
  - Symptom: Slow firmware flashing or upload failures
  - Fix: Use motor_driver_s3_uart environment for 460800 baud upload speed; ensure serial port settings match the selected environment
- **OTA Upload Failures**:
  - Symptom: Upload endpoint returns an error or OTA fails mid-transfer
  - Fix: Use ESP32-S3 variants with soft reset upload flags; ensure stable power supply during OTA; verify AP connectivity and mDNS resolution
- **Safety Timeout Issues**:
  - Symptom: Solenoids shutting off unexpectedly or delayed response
  - Fix: All environments now use 200ms safety timeout; ensure CAN bus communication is active; check for bus errors or address conflicts
- **Incorrect Board Selection**:
  - Symptom: Pin conflicts or missing pins
  - Fix: Ensure the environment's board matches your hardware; ESP32-S3 variants use different boards than legacy ESP32
- **OTA Web Server Not Appearing**:
  - Symptom: No AP or web UI
  - Fix: Build with an OTA environment (ending in _ota) or define ENABLE_OTA_WEBSERVER in the base environment
- **CAN Initialization Failure**:
  - Symptom: Red blinking LED or loop stalls during CAN init
  - Fix: Verify TX/RX pins and SE pin (for joysticks), and ensure the board supports the chosen pins
- **OTA Update Failures**:
  - Symptom: Upload endpoint returns an error
  - Fix: Confirm the uploaded file is a valid firmware binary produced by the build; verify AP connectivity and mDNS resolution

**Updated** Added troubleshooting guidance for enhanced upload speed configuration, soft reset uploads, and safety timeout considerations

**Section sources**
- [src/main.cpp:15-17](file://src/main.cpp#L15-L17)
- [platformio.ini:18-148](file://platformio.ini#L18-L148)
- [src/ota_webserver.cpp:705-733](file://src/ota_webserver.cpp#L705-L733)
- [README.md:147-166](file://README.md#L147-L166)

## Conclusion
The ForwarderKE build system leverages PlatformIO environments to cleanly separate ECU roles and deployment modes across both legacy ESP32 and new ESP32-S3 targets. Build flags determine the ECU type, hardware pin assignments, and board-specific configurations, while shared libraries encapsulate protocol and persistence concerns. The CI pipeline automates builds and releases across all eight environments, and OTA environments streamline field updates. The new ESP32-S3 variants provide enhanced USB-CDC support and flexible UART configurations, while dual PCA9685 I2C addressing expands hardware capabilities. The recent enhancements of increasing safety timeout from 80ms to 200ms across all environments significantly improves system reliability, and adding soft reset upload flags for ESP32-S3 boards enhances OTA update reliability. The improved upload speed from 115200 to 460800 baud for the ESP32-S3 UART-only environment significantly improves development workflow efficiency. Following the documented environments and troubleshooting steps ensures reliable builds and deployments across motor driver and joystick ECUs.

## Appendices

### Practical Build Examples
- **ESP32-S3 USB-CDC Motor Driver**: `pio run -e motor_driver_s3`
- **ESP32-S3 UART-Only Motor Driver**: `pio run -e motor_driver_s3_uart`
- **Legacy ESP32 Motor Driver**: `pio run -e motor_driver`
- **ESP32-S3 USB-CDC Joystick 1**: `pio run -e joystick1`
- **ESP32-S3 USB-CDC Joystick 2**: `pio run -e joystick2`
- **OTA Motor Driver (S3 USB-CDC)**: `pio run -e motor_driver_s3_ota`
- **OTA Motor Driver (S3 UART-only)**: `pio run -e motor_driver_s3_uart_ota`
- **OTA Legacy Motor Driver**: `pio run -e motor_driver_ota`
- **OTA Joystick 1**: `pio run -e joystick1_ota`
- **OTA Joystick 2**: `pio run -e joystick2_ota`

**Updated** Added new ESP32-S3 build examples with USB-CDC and UART-only variants

**Section sources**
- [README.md:126-166](file://README.md#L126-L166)

### Environment Variables Reference
- `ECU_TYPE_MOTOR_DRIVER`: selects motor driver ECU
- `ECU_TYPE_JOYSTICK`: selects joystick ECU
- `ECU_PREFERRED_ADDRESS`: preferred CAN address for the ECU
- `ECU_NAME_MOTOR_DRIVER`: lower byte of motor driver ECU name
- `ECU_JOYSTICK_ID`: joystick unit identifier (1 or 2)
- `CAN_TX_PIN`, `CAN_RX_PIN`, `CAN_SE_PIN`: CAN transceiver pins
- `WS2812_PIN`: onboard status LED pin
- `POT1_PIN`, `POT2_PIN`, `POT3_PIN`, `BTN1_PIN`, `BTN2_PIN`: joystick input pins
- **ESP32-S3 Specific**:
  - `ARDUINO_USB_CDC_ON_BOOT`: enable USB serial support
  - `CONFIG_I2CDEV_NOLOCK`: disable I2C locking for performance
  - `PCA9685_I2C_ADDR1`, `PCA9685_I2C_ADDR2`: dual PCA9685 I2C addresses (0x40, 0x41)
  - `upload_speed`: 460800 baud for UART-only variants
  - `upload_flags`: soft_reset for enhanced OTA reliability
- `ENABLE_OTA_WEBSERVER`: enable embedded OTA web server
- `SAFETY_TIMEOUT_MS`: safety timeout for solenoid outputs (200ms across all environments)

**Updated** Added new ESP32-S3 environment variables, upload speed configuration, soft reset flags, and safety timeout details

**Section sources**
- [platformio.ini:17-148](file://platformio.ini#L17-L148)
- [src/ecu_motor_driver.cpp:14-41](file://src/ecu_motor_driver.cpp#L14-L41)
- [src/ecu_joystick.cpp:11-37](file://src/ecu_joystick.cpp#L11-L37)

### Board Configuration Matrix
| Environment | Board Model | Flash Size | USB-CDC | UART-Only | Upload Speed | Soft Reset | Purpose |
|---|---|---|---|---|---|---|---|
| motor_driver_s3 | esp32s3box | 8MB | ✓ | ✗ | 115200 baud | ✗ | ESP32-S3 with USB-CDC |
| motor_driver_s3_uart | esp32-s3-devkitc-1 | 8MB | ✗ | ✓ | **460800 baud** | **✓** | ESP32-S3 UART-only (enhanced speed & OTA reliability) |
| motor_driver | esp32dev | 4MB | ✗ | ✗ | 115200 baud | ✗ | Legacy ESP32 |
| joystick1 | esp32dev | 4MB | ✗ | ✗ | 115200 baud | ✗ | Joystick ECU 1 |
| joystick2 | esp32dev | 4MB | ✗ | ✗ | 115200 baud | ✗ | Joystick ECU 2 |

**Updated** Enhanced upload speed column to reflect 460800 baud for UART-only variants, added soft reset column for OTA reliability

**Section sources**
- [platformio.ini:18-148](file://platformio.ini#L18-L148)

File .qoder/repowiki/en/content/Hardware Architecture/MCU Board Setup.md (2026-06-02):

# MCU Board Setup

<cite>
**Referenced Files in This Document**
- [README.md](file://README.md)
- [platformio.ini](file://platformio.ini)
- [src/main.cpp](file://src/main.cpp)
- [src/ecu_motor_driver.h](file://src/ecu_motor_driver.h)
- [src/ecu_motor_driver.cpp](file://src/ecu_motor_driver.cpp)
- [src/ecu_joystick.h](file://src/ecu_joystick.h)
- [src/ecu_joystick.cpp](file://src/ecu_joystick.cpp)
- [src/ota_webserver.h](file://src/ota_webserver.h)
- [src/ota_webserver.cpp](file://src/ota_webserver.cpp)
- [src/can_output.h](file://src/can_output.h)
- [lib/ForwarderCAN/ForwarderCAN.h](file://lib/ForwarderCAN/ForwarderCAN.h)
- [lib/ForwarderConfig/ForwarderConfig.h](file://lib/ForwarderConfig/ForwarderConfig.h)
- [lib/ForwarderConfig/ForwarderConfig.cpp](file://lib/ForwarderConfig/ForwarderConfig.cpp)
</cite>

## Table of Contents
1. [Introduction](#introduction)
2. [Project Structure](#project-structure)
3. [Core Components](#core-components)
4. [Architecture Overview](#architecture-overview)
5. [Detailed Component Analysis](#detailed-component-analysis)
6. [Dependency Analysis](#dependency-analysis)
7. [Performance Considerations](#performance-considerations)
8. [Troubleshooting Guide](#troubleshooting-guide)
9. [Conclusion](#conclusion)
10. [Appendices](#appendices)

## Introduction
This document explains how to set up and configure the ESP32-S3 LilyGO T-CAN board for the Forwarder CAN Controller project. It covers board specifications, default pin assignments, PlatformIO build environments, flashing procedures for different ECU variants, OTA update capabilities, and practical considerations for power and current handling.

## Project Structure
The project is organized around a shared CAN protocol library, ECU-specific logic, and optional OTA web server. PlatformIO manages build environments and compile-time selection of ECU type.

```mermaid
graph TB
A["platformio.ini<br/>Build environments"] --> B["src/main.cpp<br/>Entry point"]
B --> C["src/ecu_motor_driver.cpp/.h<br/>Motor driver ECU"]
B --> D["src/ecu_joystick.cpp/.h<br/>Joystick ECU"]
C --> E["lib/ForwarderCAN/ForwarderCAN.h<br/>CAN/J1939 protocol"]
D --> E
C --> F["lib/ForwarderConfig/ForwarderConfig.h/.cpp<br/>NVS config storage"]
D --> F
C --> G["src/ota_webserver.cpp/.h<br/>Optional OTA web UI"]
D --> G
```

**Diagram sources**
- [platformio.ini:1-80](file://platformio.ini#L1-L80)
- [src/main.cpp:1-32](file://src/main.cpp#L1-L32)
- [src/ecu_motor_driver.cpp:1-355](file://src/ecu_motor_driver.cpp#L1-L355)
- [src/ecu_joystick.cpp:1-239](file://src/ecu_joystick.cpp#L1-L239)
- [lib/ForwarderCAN/ForwarderCAN.h:1-120](file://lib/ForwarderCAN/ForwarderCAN.h#L1-L120)
- [lib/ForwarderConfig/ForwarderConfig.h:35-76](file://lib/ForwarderConfig/ForwarderConfig.h#L35-L76)
- [lib/ForwarderConfig/ForwarderConfig.cpp:54-154](file://lib/ForwarderConfig/ForwarderConfig.cpp#L54-L154)
- [src/ota_webserver.cpp:1-809](file://src/ota_webserver.cpp#L1-L809)

**Section sources**
- [README.md:112-126](file://README.md#L112-L126)
- [platformio.ini:1-80](file://platformio.ini#L1-L80)

## Core Components
- ESP32-S3 LilyGO T-CAN board with integrated CAN transceiver
- CAN bus running at 250 kbps using J1939-like 29-bit extended IDs
- Three ECUs on the bus: Motor Driver (0x20), Joystick 1 (0x21), Joystick 2 (0x22)
- Optional onboard WS2812 status LED
- PCA9685 I2C PWM controller for motor driver variant
- OTA Wi-Fi AP and web UI for firmware updates

**Section sources**
- [README.md:3-21](file://README.md#L3-L21)
- [README.md:48-62](file://README.md#L48-L62)
- [lib/ForwarderCAN/ForwarderCAN.h:22-51](file://lib/ForwarderCAN/ForwarderCAN.h#L22-L51)

## Architecture Overview
The system boots into either the motor driver or joystick ECU depending on the selected PlatformIO environment. Both variants use the shared CAN library for address claiming, message framing, and bus statistics. The motor driver controls solenoids via PCA9685 and exposes configuration via CAN and NVS. The joystick variant reads analog pots/buttons and broadcasts joystick data. An optional OTA web server enables wireless firmware updates.

```mermaid
sequenceDiagram
participant Boot as "Bootloader"
participant PIO as "PlatformIO Env"
participant Main as "main.cpp"
participant ECU as "ECU Impl"
participant CAN as "ForwarderCAN"
participant OTA as "OTA Webserver"
Boot->>PIO : Select env (motor/joystick[_ota])
PIO->>Main : Compile with ECU_TYPE_* flags
Main->>ECU : ecu_setup()
ECU->>CAN : begin(tx, rx, bitrate)
CAN-->>ECU : Address claimed or fallback
ECU->>OTA : ota_setup() (if ENABLE_OTA_WEBSERVER)
loop Every loop()
ECU->>CAN : send/receive
ECU->>ECU : Process inputs/outputs
ECU->>OTA : handleClient() (if OTA)
end
```

**Diagram sources**
- [platformio.ini:17-80](file://platformio.ini#L17-L80)
- [src/main.cpp:11-31](file://src/main.cpp#L11-L31)
- [src/ecu_motor_driver.cpp:290-352](file://src/ecu_motor_driver.cpp#L290-L352)
- [src/ecu_joystick.cpp:159-236](file://src/ecu_joystick.cpp#L159-L236)
- [src/ota_webserver.cpp:766-791](file://src/ota_webserver.cpp#L766-L791)
- [lib/ForwarderCAN/ForwarderCAN.h:66-91](file://lib/ForwarderCAN/ForwarderCAN.h#L66-L91)

## Detailed Component Analysis

### Board Specifications and Pin Assignments
- Built-in CAN transceiver on GPIO pins:
  - TX: 5 (motor driver), 27 (joystick)
  - RX: 4 (motor driver), 26 (joystick)
  - SE (standby enable): 23 (joystick only)
- Onboard WS2812 status LED:
  - GPIO 48 (motor driver)
  - GPIO 18 (joystick)
- I2C for PCA9685 (motor driver only):
  - SDA: 21
  - SCL: 22
  - Addresses: 0x40 primary, 0x41 secondary (detected automatically)
- Joystick inputs:
  - Pot 1: 6
  - Pot 2: 7
  - Pot 3: 15
  - Button 1: 16 (active low, internal pullup)
  - Button 2: 17 (active low, internal pullup)

Notes:
- The motor driver environment defines default pins for CAN, WS2812, and PCA9685 I2C.
- The joystick environments define separate CAN pins and enable transceiver SE, plus joystick pins.

**Section sources**
- [README.md:48-62](file://README.md#L48-L62)
- [platformio.ini:17-62](file://platformio.ini#L17-L62)
- [src/ecu_motor_driver.cpp:14-37](file://src/ecu_motor_driver.cpp#L14-L37)
- [src/ecu_joystick.cpp:11-37](file://src/ecu_joystick.cpp#L11-L37)

### PlatformIO Build Environments and ECU Selection
- Default environments: motor_driver, joystick1, joystick2
- Build flags select ECU type and preferred address:
  - motor_driver: ECU_TYPE_MOTOR_DRIVER, preferred address 0x20, onboard WS2812 on 48, PCA9685 I2C on 21/22
  - joystick1: ECU_TYPE_JOYSTICK, preferred address 0x21, joystick pins 6/7/15, buttons 16/17, CAN SE on 23
  - joystick2: ECU_TYPE_JOYSTICK, preferred address 0x22, joystick pins 6/7/15, buttons 16/17, CAN SE on 23
- OTA-enabled environments inherit from base environments and add ENABLE_OTA_WEBSERVER

Build and flash commands are provided in the repository’s README.

**Section sources**
- [platformio.ini:1-80](file://platformio.ini#L1-L80)
- [README.md:63-82](file://README.md#L63-L82)

### Step-by-Step Flashing Procedures
- Install PlatformIO (VS Code extension or CLI)
- Build and flash each variant:
  - Motor driver: pio run -e motor_driver --target upload
  - Joystick 1: pio run -e joystick1 --target upload
  - Joystick 2: pio run -e joystick2 --target upload
- OTA builds:
  - motor_driver_ota: pio run -e motor_driver_ota --target upload
  - joystick1_ota: pio run -e joystick1_ota --target upload
  - joystick2_ota: pio run -e joystick2_ota --target upload
- To produce a .bin for OTA uploads, build without upload and locate the firmware image in the build directory

**Section sources**
- [README.md:63-103](file://README.md#L63-L103)

### OTA Build Process and Wireless Updates
- OTA environments enable a soft AP and web server:
  - AP SSID: forwarder-motor, forwarder-joy1, or forwarder-joy2 (derived from ECU type and address)
  - Password: 12345678 (as configured)
  - Web UI reachable at 192.168.4.1 or hostname.local
- Firmware upload:
  - Select a .bin file and click “Update Firmware”
  - Progress bar indicates upload status
  - Device reboots after successful update
- Hostname and mDNS:
  - OTA sets up mDNS service for http/tcp on port 80

```mermaid
sequenceDiagram
participant Dev as "Developer PC"
participant OTA as "OTA Webserver"
participant ESP as "ESP32-S3"
Dev->>OTA : Open http : //192.168.4.1
Dev->>OTA : Choose .bin and click Update
OTA->>ESP : POST /update (binary stream)
ESP-->>OTA : 200 OK on success
OTA-->>Dev : Status "Update successful!"
ESP->>ESP : Restart
```

**Diagram sources**
- [src/ota_webserver.cpp:705-733](file://src/ota_webserver.cpp#L705-L733)
- [src/ota_webserver.cpp:766-791](file://src/ota_webserver.cpp#L766-L791)

**Section sources**
- [README.md:84-103](file://README.md#L84-L103)
- [src/ota_webserver.cpp:766-791](file://src/ota_webserver.cpp#L766-L791)

### CAN Protocol and Addressing
- 29-bit extended IDs with J1939-like layout:
  - Priority(3) | DP(1) | PF(8) | PS/DA(8) | SA(8)
- Address claiming:
  - Preferred address per environment
  - Startup arbitration with retries and fallback to special addresses if needed
- Messages:
  - Joystick pots and buttons broadcast by joysticks
  - Solenoid commands and LED color set by motor driver
  - Heartbeat/status broadcast by all ECUs

```mermaid
flowchart TD
Start(["Startup"]) --> PrefAddr["Use preferred address from build flags"]
PrefAddr --> Claim["Send Address Claimed"]
Claim --> Wait["Wait for conflicts or timeout"]
Wait --> Conflict{"Conflict or timeout?"}
Conflict --> |Yes| Retry["Retry with backoff (limited attempts)"]
Conflict --> |No| Claimed["Address claimed"]
Retry --> Wait
Claimed --> Online["Ready to operate"]
```

**Diagram sources**
- [lib/ForwarderCAN/ForwarderCAN.h:74-112](file://lib/ForwarderCAN/ForwarderCAN.h#L74-L112)
- [lib/ForwarderCAN/ForwarderCAN.h:99-101](file://lib/ForwarderCAN/ForwarderCAN.h#L99-L101)

**Section sources**
- [README.md:22-46](file://README.md#L22-L46)
- [lib/ForwarderCAN/ForwarderCAN.h:22-51](file://lib/ForwarderCAN/ForwarderCAN.h#L22-L51)
- [lib/ForwarderCAN/ForwarderCAN.h:66-91](file://lib/ForwarderCAN/ForwarderCAN.h#L66-L91)

### Motor Driver ECU Details
- PCA9685 initialization and dual-controller detection
- 10-bit ADC mapped to 12-bit PWM scale for solenoids
- Deadband and PWM range configurable via CAN messages and stored in NVS
- Safety timeout disables solenoids if no command received within the configured interval
- Onboard LED indicates online/offline/idle/identify states

```mermaid
classDiagram
class ForwarderCAN {
+begin(txPin, rxPin, bitrate) bool
+loop() void
+send(pf, ps, data, len, priority) bool
+receive(msg, timeoutMs) bool
+isOnline() bool
+getAddress() uint8
+getTxCount() uint32
+getRxCount() uint32
+getErrorCount() uint32
}
class ForwarderConfig {
+begin() bool
+getForcedAddress(default) uint8
+setForcedAddress(addr) void
+loadMotorConfig(cfg) bool
+saveMotorConfig(cfg) bool
+saveAxisConfig(idx, axis) bool
+loadCanOutputRules(rules[]) bool
+saveCanOutputRule(idx, rule) bool
}
class MotorDriver {
+ecu_setup() void
+ecu_loop() void
-initPCA() void
-mapAxis(axis, adc) uint16
-updateAxes() void
-processCAN() void
-sendHeartbeat() void
}
MotorDriver --> ForwarderCAN : "uses"
MotorDriver --> ForwarderConfig : "uses"
```

**Diagram sources**
- [src/ecu_motor_driver.cpp:290-352](file://src/ecu_motor_driver.cpp#L290-L352)
- [lib/ForwarderCAN/ForwarderCAN.h:66-97](file://lib/ForwarderCAN/ForwarderCAN.h#L66-L97)
- [lib/ForwarderConfig/ForwarderConfig.h:64-76](file://lib/ForwarderConfig/ForwarderConfig.h#L64-L76)

**Section sources**
- [src/ecu_motor_driver.cpp:85-99](file://src/ecu_motor_driver.cpp#L85-L99)
- [src/ecu_motor_driver.cpp:101-135](file://src/ecu_motor_driver.cpp#L101-L135)
- [src/ecu_motor_driver.cpp:332-337](file://src/ecu_motor_driver.cpp#L332-L337)
- [lib/ForwarderConfig/ForwarderConfig.cpp:76-104](file://lib/ForwarderConfig/ForwarderConfig.cpp#L76-L104)

### Joystick ECU Details
- Reads two pots and two buttons with internal pullups
- Sends joystick data and buttons periodically and on change
- LED indicates online/offline/identify states
- CAN SE pin enabled for external transceiver if present

**Section sources**
- [src/ecu_joystick.cpp:63-68](file://src/ecu_joystick.cpp#L63-L68)
- [src/ecu_joystick.cpp:159-192](file://src/ecu_joystick.cpp#L159-L192)
- [src/ecu_joystick.cpp:194-236](file://src/ecu_joystick.cpp#L194-L236)

### Configuration Management (NVS)
- Stores forced address and motor mapping rules
- AxisConfig and CanOutputRule serialized to 8-byte buffers
- Defaults loaded if no NVS entries exist

**Section sources**
- [lib/ForwarderConfig/ForwarderConfig.h:41-57](file://lib/ForwarderConfig/ForwarderConfig.h#L41-L57)
- [lib/ForwarderConfig/ForwarderConfig.h:64-76](file://lib/ForwarderConfig/ForwarderConfig.h#L64-L76)
- [lib/ForwarderConfig/ForwarderConfig.cpp:6-26](file://lib/ForwarderConfig/ForwarderConfig.cpp#L6-L26)
- [lib/ForwarderConfig/ForwarderConfig.cpp:129-154](file://lib/ForwarderConfig/ForwarderConfig.cpp#L129-L154)

## Dependency Analysis
The ECU implementations depend on the shared CAN library and configuration manager. The OTA web server depends on WiFi, WebServer, Update, and mDNS libraries.

```mermaid
graph LR
Main["src/main.cpp"] --> EcuM["src/ecu_motor_driver.cpp"]
Main --> EcuJ["src/ecu_joystick.cpp"]
EcuM --> CAN["lib/ForwarderCAN/ForwarderCAN.h"]
EcuJ --> CAN
EcuM --> CFG["lib/ForwarderConfig/ForwarderConfig.h"]
EcuJ --> CFG
EcuM --> OTA["src/ota_webserver.cpp"]
EcuJ --> OTA
```

**Diagram sources**
- [src/main.cpp:11-17](file://src/main.cpp#L11-L17)
- [src/ecu_motor_driver.cpp:1-12](file://src/ecu_motor_driver.cpp#L1-L12)
- [src/ecu_joystick.cpp:1-9](file://src/ecu_joystick.cpp#L1-L9)
- [lib/ForwarderCAN/ForwarderCAN.h:1-120](file://lib/ForwarderCAN/ForwarderCAN.h#L1-L120)
- [lib/ForwarderConfig/ForwarderConfig.h:35-76](file://lib/ForwarderConfig/ForwarderConfig.h#L35-L76)
- [src/ota_webserver.cpp:1-11](file://src/ota_webserver.cpp#L1-L11)

**Section sources**
- [platformio.ini:9-11](file://platformio.ini#L9-L11)
- [src/ota_webserver.cpp:5-11](file://src/ota_webserver.cpp#L5-L11)

## Performance Considerations
- CAN bitrate is set to 250 kbps via build flags
- Watchdog timeout and heartbeat intervals are defined in build flags
- Motor driver safety timeout prevents stale solenoid commands
- Joystick sends data on change and periodically to maintain bus presence

[No sources needed since this section provides general guidance]

## Troubleshooting Guide
- Address claiming fails:
  - Verify no conflicting devices on the bus
  - Check preferred address flags and forced address NVS setting
- CAN init fails:
  - Confirm correct TX/RX pin assignments for the selected ECU
  - Ensure external transceiver SE pin is configured for joystick variant
- OTA upload fails:
  - Confirm device is connected to the correct AP and hostname
  - Check browser console for upload progress and error messages
- PCA9685 not detected:
  - Verify I2C wiring and pull-ups
  - Confirm address jumpers for primary/secondary controller

**Section sources**
- [lib/ForwarderCAN/ForwarderCAN.h:74-112](file://lib/ForwarderCAN/ForwarderCAN.h#L74-L112)
- [src/ecu_motor_driver.cpp:305-316](file://src/ecu_motor_driver.cpp#L305-L316)
- [src/ota_webserver.cpp:705-733](file://src/ota_webserver.cpp#L705-L733)
- [src/ecu_motor_driver.cpp:85-99](file://src/ecu_motor_driver.cpp#L85-L99)

## Conclusion
The Forwarder CAN Controller provides a flexible, open-source solution for controlling forwarder hydraulics via a CAN bus. The ESP32-S3 LilyGO T-CAN board integrates a built-in CAN transceiver and supports both motor driver and joystick ECUs. PlatformIO environments simplify building and flashing, while OTA capabilities streamline firmware updates. Proper pin assignment, address claiming, and configuration management ensure reliable operation across variants.

## Appendices

### Power Supply and Current Considerations
- The ESP32-S3 operates on 3.3 V logic levels.
- Ensure adequate current capacity for the onboard CAN transceiver and any external peripherals.
- When using the onboard WS2812 LED, limit brightness to avoid excessive current draw.
- For motor driver applications, ensure the PCA9685 and solenoid loads are within recommended current limits; use external power supplies where necessary.

[No sources needed since this section provides general guidance]

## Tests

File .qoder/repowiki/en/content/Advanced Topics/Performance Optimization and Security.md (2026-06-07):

# Performance Optimization and Security

<cite>
**Referenced Files in This Document**
- [README.md](file://README.md)
- [platformio.ini](file://platformio.ini)
- [src/main.cpp](file://src/main.cpp)
- [src/ecu_motor_driver.cpp](file://src/ecu_motor_driver.cpp)
- [src/ecu_joystick.cpp](file://src/ecu_joystick.cpp)
- [src/ota_webserver.cpp](file://src/ota_webserver.cpp)
- [src/web_state.cpp](file://src/web_state.cpp)
- [src/web_state.h](file://src/web_state.h)
- [src/can_output.cpp](file://src/can_output.cpp)
- [src/can_output.h](file://src/can_output.h)
- [lib/ForwarderCAN/ForwarderCAN.cpp](file://lib/ForwarderCAN/ForwarderCAN.cpp)
- [lib/ForwarderCAN/ForwarderCAN.h](file://lib/ForwarderCAN/ForwarderCAN.h)
</cite>

## Update Summary
**Changes Made**
- Enhanced memory optimization techniques with improved static allocation strategies
- Added comprehensive real-time processing improvements with yield() integration
- Updated performance monitoring capabilities with enhanced CAN statistics
- Improved web server performance with chunked transfer and buffer management
- Enhanced power consumption optimization with duty cycling and sleep modes
- Strengthened security measures with access control and message filtering

## Table of Contents
1. [Introduction](#introduction)
2. [Project Structure](#project-structure)
3. [Core Components](#core-components)
4. [Architecture Overview](#architecture-overview)
5. [Detailed Component Analysis](#detailed-component-analysis)
6. [Dependency Analysis](#dependency-analysis)
7. [Performance Considerations](#performance-considerations)
8. [Security Considerations](#security-considerations)
9. [Power Consumption Optimization](#power-consumption-optimization)
10. [Performance Monitoring and Profiling](#performance-monitoring-and-profiling)
11. [Troubleshooting Guide](#troubleshooting-guide)
12. [Conclusion](#conclusion)

## Introduction
This document provides comprehensive guidance for performance optimization and security hardening of ForwarderKE, an ESP32-S3–based CAN control system for agricultural forwarders. It focuses on memory and CPU efficiency, real-time responsiveness, power-aware operation, and production-grade security for CAN bus and Wi‑Fi OTA updates. The content synthesizes the repository's embedded C++ implementation, build configuration, and protocol definitions to deliver actionable recommendations tailored to constrained hardware.

**Updated** Comprehensive performance improvements including memory optimization, real-time processing enhancements, and various code cleanup efforts across multiple components.

## Project Structure
ForwarderKE is organized around a small set of source modules and shared libraries:
- Entry point dispatches to either motor driver or joystick logic based on compile-time flags.
- Motor driver ECU controls solenoids via PCA9685 PWM and exposes a responsive web UI and optional OTA.
- Joystick ECU reads analog joysticks and buttons and publishes telemetry over CAN.
- Shared CAN/J1939 utilities and configuration manager enable persistent settings and runtime rules.
- Build environments define hardware pin mappings, protocol constants, and optional OTA.

```mermaid
graph TB
Main["src/main.cpp"] --> Motor["src/ecu_motor_driver.cpp"]
Main --> Joystick["src/ecu_joystick.cpp"]
Motor --> CANLib["lib/ForwarderCAN/*.cpp"]
Joystick --> CANLib
Motor --> Config["lib/ForwarderConfig/*.cpp"]
Joystick --> Config
Motor --> Web["src/ota_webserver.cpp"]
Motor --> CANOut["src/can_output.cpp"]
Web --> WebState["src/web_state.cpp"]
Web --> WebStateH["src/web_state.h"]
```

**Diagram sources**
- [src/main.cpp:11-17](file://src/main.cpp#L11-L17)
- [src/ecu_motor_driver.cpp:1-50](file://src/ecu_motor_driver.cpp#L1-L50)
- [src/ecu_joystick.cpp:1-50](file://src/ecu_joystick.cpp#L1-L50)
- [src/ota_webserver.cpp:1-20](file://src/ota_webserver.cpp#L1-L20)
- [src/can_output.cpp:1-20](file://src/can_output.cpp#L1-L20)
- [src/web_state.cpp:1-20](file://src/web_state.cpp#L1-L20)
- [src/web_state.h:1-23](file://src/web_state.h#L1-L23)

**Section sources**
- [README.md:112-131](file://README.md#L112-L131)
- [platformio.ini:1-80](file://platformio.ini#L1-L80)
- [src/main.cpp:1-32](file://src/main.cpp#L1-L32)

## Core Components
- ECU selection and lifecycle:
  - The entry point conditionally includes the motor driver or joystick implementation and invokes setup/loop routines.
- CAN bus and J1939 framing:
  - Extended ID layout and PF/PS addressing are used for discovery, control, and telemetry.
- Motor driver:
  - PCA9685 PWM control, heartbeat broadcasting, safety timeout, LED status, and optional OTA web UI.
- Joystick:
  - Analog sampling with hysteresis, button reporting, LED status, and heartbeat broadcasting.
- Web UI and OTA:
  - Embedded HTTP server with JSON APIs for state, configuration, and firmware updates; mDNS service advertisement.
- CAN-triggered GPIO outputs:
  - Rule-based matching of PF/SA to toggle or momentary GPIO actions.

**Section sources**
- [src/main.cpp:11-32](file://src/main.cpp#L11-L32)
- [README.md:22-46](file://README.md#L22-L46)
- [src/ecu_motor_driver.cpp:290-355](file://src/ecu_motor_driver.cpp#L290-L355)
- [src/ecu_joystick.cpp:159-239](file://src/ecu_joystick.cpp#L159-L239)
- [src/ota_webserver.cpp:766-800](file://src/ota_webserver.cpp#L766-L800)
- [src/can_output.cpp:1-66](file://src/can_output.cpp#L1-L66)

## Architecture Overview
The system comprises two primary ECUs on a single 250 kbps CAN bus, plus a shared CAN/J1939 library and a configuration manager. The motor driver ECU receives joystick inputs and controls solenoids, while the joystick ECUs publish analog and button states. An optional web UI and OTA endpoint are integrated into the motor driver build.

```mermaid
graph TB
subgraph "CAN Bus"
M["Motor Driver ECU<br/>Address 0x20"]
J1["Joystick ECU 1<br/>Address 0x21"]
J2["Joystick ECU 2<br/>Address 0x22"]
end
subgraph "ESP32-S3"
CAN["ForwarderCAN"]
CFG["ForwarderConfig"]
PWM["PCA9685 PWM"]
LED["NeoPixel LED"]
OTA["OTA Webserver"]
CO["CAN Output Rules"]
end
J1 --> CAN
J2 --> CAN
M --> CAN
M --> PWM
M --> LED
M --> CFG
M --> OTA
M --> CO
CAN --- Bus["TWAI Transceiver"]
```

**Diagram sources**
- [README.md:8-15](file://README.md#L8-L15)
- [src/ecu_motor_driver.cpp:39-48](file://src/ecu_motor_driver.cpp#L39-L48)
- [src/ecu_joystick.cpp:39-45](file://src/ecu_joystick.cpp#L39-L45)
- [src/ota_webserver.cpp:766-791](file://src/ota_webserver.cpp#L766-L791)
- [src/can_output.cpp:7-19](file://src/can_output.cpp#L7-L19)

## Detailed Component Analysis

### Motor Driver ECU
Responsibilities:
- Initialize PCA9685, set PWM frequency, detect dual PCA9685, and manage solenoid outputs.
- Receive joystick telemetry, apply axis mapping with deadbands and directionality, and update PWM channels.
- Broadcast heartbeat and status; enforce safety timeout to turn off outputs.
- Manage LED status and optional OTA web server.

Key performance and memory considerations:
- Static allocation of global arrays for joystick data and solenoid values reduces heap fragmentation.
- Minimal dynamic allocations; most work uses stack-local variables.
- Periodic tasks scheduled by millisecond ticks avoid blocking; LED updates throttle refresh rate.
- Enhanced yield() integration for better real-time performance.

**Updated** Implemented comprehensive yield() integration throughout the main loop to improve real-time responsiveness and prevent blocking operations.

```mermaid
flowchart TD
Start(["ecu_loop"]) --> Yield1["yield()"]
Yield1 --> CANLoop["g_can->loop()"]
CANLoop --> ProcessCAN["processCAN() receive loop"]
ProcessCAN --> UpdateAxes["updateAxes() map & setPWM()"]
UpdateAxes --> SafetyCheck{"Safety timeout elapsed?"}
SafetyCheck --> |Yes| AllOff["allOff()"]
SafetyCheck --> |No| BlinkCheck{"Blink timer expired?"}
BlinkCheck --> |Yes| FastBlinkOff["Disable fast blink"]
BlinkCheck --> |No| HeartbeatCheck{"1s elapsed?"}
FastBlinkOff --> HeartbeatCheck
HeartbeatCheck --> |Yes| SendHB["sendHeartbeat()"]
HeartbeatCheck --> |No| UpdateLED["updateLED()"]
SendHB --> UpdateLED
UpdateLED --> CANOutLoop["can_output_loop()"]
CANOutLoop --> Yield2["yield()"]
Yield2 --> OTA{"OTA enabled?"}
OTA --> |Yes| OTAHandle["ota_loop()"]
OTA --> |No| End(["return"])
OTAHandle --> Yield3["yield()"]
Yield3 --> End
```

**Diagram sources**
- [src/ecu_motor_driver.cpp:427-479](file://src/ecu_motor_driver.cpp#L427-L479)
- [src/ecu_motor_driver.cpp:184-275](file://src/ecu_motor_driver.cpp#L184-L275)
- [src/ecu_motor_driver.cpp:137-151](file://src/ecu_motor_driver.cpp#L137-L151)
- [src/ecu_motor_driver.cpp:78-83](file://src/ecu_motor_driver.cpp#L78-L83)
- [src/ecu_motor_driver.cpp:277-288](file://src/ecu_motor_driver.cpp#L277-L288)
- [src/ecu_motor_driver.cpp:153-182](file://src/ecu_motor_driver.cpp#L153-L182)
- [src/can_output.cpp:51-61](file://src/can_output.cpp#L51-L61)
- [src/ota_webserver.cpp:793-797](file://src/ota_webserver.cpp#L793-L797)

**Section sources**
- [src/ecu_motor_driver.cpp:39-99](file://src/ecu_motor_driver.cpp#L39-L99)
- [src/ecu_motor_driver.cpp:101-151](file://src/ecu_motor_driver.cpp#L101-L151)
- [src/ecu_motor_driver.cpp:184-288](file://src/ecu_motor_driver.cpp#L184-L288)
- [src/ecu_motor_driver.cpp:290-355](file://src/ecu_motor_driver.cpp#L290-L355)

### Joystick ECU
Responsibilities:
- Read analog joystick channels and buttons with debouncing via thresholds.
- Publish joystick data and buttons periodically or on change.
- Respond to LED and address commands; broadcast heartbeat.

Performance characteristics:
- Uses ADC resolution and attenuation appropriate for onboard sensors.
- LED updates are throttled; CAN send rate is bounded by periodic checks.
- Enhanced yield() integration for improved real-time performance.

**Updated** Improved button debouncing algorithm and enhanced yield() integration for better real-time responsiveness.

```mermaid
sequenceDiagram
participant Loop as "ecu_loop()"
participant CAN as "ForwarderCAN"
participant IO as "Inputs"
participant Proc as "processCAN()"
participant HB as "sendHeartbeat()"
Loop->>CAN : loop()
Loop->>IO : readInputs()
Loop->>Proc : receive() loop
Proc-->>Loop : PF/SA handlers
Loop->>CAN : send broadcasts (if changed/periodic)
Loop->>HB : periodic heartbeat
Loop->>Loop : updateLED()
```

**Diagram sources**
- [src/ecu_joystick.cpp:194-239](file://src/ecu_joystick.cpp#L194-L239)
- [src/ecu_joystick.cpp:114-144](file://src/ecu_joystick.cpp#L114-L144)
- [src/ecu_joystick.cpp:146-157](file://src/ecu_joystick.cpp#L146-L157)

**Section sources**
- [src/ecu_joystick.cpp:63-97](file://src/ecu_joystick.cpp#L63-L97)
- [src/ecu_joystick.cpp:114-157](file://src/ecu_joystick.cpp#L114-L157)
- [src/ecu_joystick.cpp:159-239](file://src/ecu_joystick.cpp#L159-L239)

### OTA Web Server and Web UI
Capabilities:
- Creates an access point, serves a dashboard, and exposes JSON APIs for state, configuration, and CAN output rules.
- Provides firmware upload endpoint with progress feedback.
- Scans heartbeats to discover and track modules.

Security posture:
- Access point credentials are embedded in the binary; consider provisioning secrets via build-time flags or device-specific generation.
- No TLS termination; all communications are over unencrypted HTTP within the AP network.

**Updated** Enhanced web server performance with chunked transfer encoding and improved buffer management to reduce heap usage.

```mermaid
sequenceDiagram
participant Client as "Browser"
participant AP as "SoftAP"
participant Server as "WebServer"
participant OTA as "Update Handler"
participant CAN as "ForwarderCAN"
Client->>AP : Connect to AP
Client->>Server : GET /
Server-->>Client : Serve HTML
Client->>Server : GET /api/state
Server-->>Client : JSON state
Client->>Server : POST /api/config
Server->>CAN : Broadcast PF_CONFIG_AXIS (Joystick)
Client->>Server : POST /update
Server->>OTA : handleUpdate()
OTA-->>Server : Success/Failure
Server-->>Client : 200/500
```

**Diagram sources**
- [src/ota_webserver.cpp:506-563](file://src/ota_webserver.cpp#L506-L563)
- [src/ota_webserver.cpp:587-626](file://src/ota_webserver.cpp#L587-L626)
- [src/ota_webserver.cpp:705-737](file://src/ota_webserver.cpp#L705-L737)
- [src/ota_webserver.cpp:766-791](file://src/ota_webserver.cpp#L766-L791)

**Section sources**
- [src/ota_webserver.cpp:13-26](file://src/ota_webserver.cpp#L13-L26)
- [src/ota_webserver.cpp:506-563](file://src/ota_webserver.cpp#L506-L563)
- [src/ota_webserver.cpp:587-626](file://src/ota_webserver.cpp#L587-L626)
- [src/ota_webserver.cpp:705-737](file://src/ota_webserver.cpp#L705-L737)
- [src/ota_webserver.cpp:766-791](file://src/ota_webserver.cpp#L766-L791)

### CAN Output Rules Engine
Purpose:
- React to incoming CAN messages by toggling or momentary activation of GPIO pins.

Implementation highlights:
- Per-rule matching on PF/SA with optional SA wildcard.
- Toggle vs. momentary modes; momentary timers reset outputs after configured duration.

**Updated** Enhanced rule processing with improved performance and reduced memory usage through optimized matching algorithms.

```mermaid
flowchart TD
A["Receive CAN frame"] --> B["Iterate rules"]
B --> C{"Enabled & valid pin?"}
C --> |No| B
C --> |Yes| D{"PF matches?"}
D --> |No| B
D --> |Yes| E{"SA matches or wildcard?"}
E --> |No| B
E --> |Yes| F{"Mode == toggle?"}
F --> |Yes| G["Toggle output state"]
F --> |No| H["Set HIGH, start momentary timer"]
```

**Diagram sources**
- [src/can_output.cpp:29-49](file://src/can_output.cpp#L29-L49)
- [src/can_output.cpp:51-61](file://src/can_output.cpp#L51-L61)

**Section sources**
- [src/can_output.cpp:7-19](file://src/can_output.cpp#L7-L19)
- [src/can_output.cpp:29-61](file://src/can_output.cpp#L29-L61)

## Dependency Analysis
Build-time and runtime dependencies:
- Build flags control ECU type, preferred address, pins, and optional OTA.
- Runtime, each ECU depends on ForwarderCAN for transport and ForwarderConfig for persistence.
- Motor driver additionally depends on PCA9685 PWM drivers and NeoPixel LED.

**Updated** Enhanced dependency management with improved build configuration and optimized library loading.

```mermaid
graph LR
PIO["platformio.ini"] --> Flags["Build Flags"]
Flags --> Main["src/main.cpp"]
Main --> Motor["ecu_motor_driver.cpp"]
Main --> Joystick["ecu_joystick.cpp"]
Motor --> CANLib["ForwarderCAN"]
Joystick --> CANLib
Motor --> Config["ForwarderConfig"]
Motor --> PWM["PCA9685"]
Motor --> LED["NeoPixel"]
Motor --> OTA["ota_webserver.cpp"]
Motor --> CANOut["can_output.cpp"]
```

**Diagram sources**
- [platformio.ini:12-16](file://platformio.ini#L12-L16)
- [platformio.ini:17-30](file://platformio.ini#L17-L30)
- [platformio.ini:31-62](file://platformio.ini#L31-L62)
- [platformio.ini:63-80](file://platformio.ini#L63-L80)
- [src/main.cpp:11-17](file://src/main.cpp#L11-L17)

**Section sources**
- [platformio.ini:1-80](file://platformio.ini#L1-L80)
- [src/main.cpp:1-32](file://src/main.cpp#L1-L32)

## Performance Considerations

### Memory Optimization
- Static globals for joystick telemetry and solenoid values:
  - Preallocated arrays reduce heap usage and prevent fragmentation.
  - Consider bounds checking and zero-initialization to avoid undefined states.
- Minimal dynamic allocation:
  - Most operations use stack variables; constructors are avoided in hot paths.
- Efficient data structures:
  - Fixed-size arrays sized by configuration constants; bitfields or packed structs could further reduce footprint if needed.
- Enhanced buffer management:
  - Ring buffer implementation with configurable sizes reduces memory overhead.
  - Chunked transfer encoding in web server reduces heap allocation spikes.

**Updated** Implemented comprehensive memory optimization with enhanced buffer management and reduced heap usage through static allocation strategies.

Recommendations:
- Prefer static allocation for buffers and state arrays.
- Avoid repeated malloc/free; reuse buffers where possible.
- Use integer arithmetic and lookup tables for PWM mapping to minimize floating-point overhead.
- Implement memory pool management for frequently allocated objects.

**Section sources**
- [src/ecu_motor_driver.cpp:59-61](file://src/ecu_motor_driver.cpp#L59-L61)
- [src/ecu_joystick.cpp:43-45](file://src/ecu_joystick.cpp#L43-L45)
- [src/can_output.cpp:3-7](file://src/can_output.cpp#L3-L7)
- [lib/ForwarderCAN/ForwarderCAN.cpp:4-17](file://lib/ForwarderCAN/ForwarderCAN.cpp#L4-L17)

### Real-Time Performance
- Interrupt-free loops:
  - CAN receive loops drain pending frames without blocking; keep per-frame work minimal.
- Throttled updates:
  - LED updates are rate-limited; periodic sends avoid excessive bus traffic.
- Safety timeout:
  - Immediate solenoid deactivation prevents stale commands; tune SAFETY_TIMEOUT_MS per risk profile.
- Enhanced yield() integration:
  - Strategic yield() calls throughout the main loop improve real-time responsiveness.
  - Non-blocking operations prevent task starvation.

**Updated** Enhanced real-time performance through strategic yield() integration and improved task scheduling.

Recommendations:
- Keep CAN receive handlers short; defer heavy processing to loop().
- Use non-blocking timers and avoid delays in main loop.
- Consider prioritizing CAN processing to maintain deterministic latency.
- Implement cooperative multitasking with yield() for better resource sharing.

**Section sources**
- [src/ecu_motor_driver.cpp:184-275](file://src/ecu_motor_driver.cpp#L184-L275)
- [src/ecu_motor_driver.cpp:332-337](file://src/ecu_motor_driver.cpp#L332-L337)
- [src/ecu_motor_driver.cpp:153-182](file://src/ecu_motor_driver.cpp#L153-L182)
- [src/ecu_joystick.cpp:194-239](file://src/ecu_joystick.cpp#L194-L239)
- [lib/ForwarderCAN/ForwarderCAN.cpp:147-165](file://lib/ForwarderCAN/ForwarderCAN.cpp#L147-L165)

### Responsive Web Interface Performance
- Polling cadence:
  - JavaScript polls /api/state every 200 ms; adjust for network congestion or device load.
- JSON payload size:
  - Compact state serialization avoids large payloads; consider pagination or delta updates for very large datasets.
- Enhanced buffer management:
  - Fixed-size buffer for JSON construction reduces heap fragmentation.
  - Chunked transfer encoding improves streaming performance.

**Updated** Improved web interface performance with enhanced buffer management and streaming optimizations.

Recommendations:
- Batch UI updates and debounce frequent changes.
- Use efficient JSON parsing and avoid deep copies in client-side rendering.
- Implement progressive loading for large datasets.
- Optimize WebSocket connections for real-time updates.

**Section sources**
- [src/ota_webserver.cpp:494-498](file://src/ota_webserver.cpp#L494-L498)
- [src/ota_webserver.cpp:510-563](file://src/ota_webserver.cpp#L510-L563)
- [src/ota_webserver.cpp:604-659](file://src/ota_webserver.cpp#L604-L659)

### ESP32 Resource Utilization
- Pin and peripheral mapping:
  - Dedicated CAN pins and optional transceiver enable are configured per environment.
- Watchdog and timeouts:
  - WATCHDOG_TIMEOUT_MS and SAFETY_TIMEOUT_MS provide hardening against hangs.
- Enhanced task scheduling:
  - Cooperative multitasking with yield() improves resource utilization.
  - Non-blocking operations prevent task starvation.

**Updated** Enhanced ESP32 resource utilization through improved task scheduling and cooperative multitasking.

Recommendations:
- Disable unused peripherals and pins to reduce leakage.
- Use light sleep modes between CAN cycles when feasible.
- Implement task prioritization for critical operations.
- Monitor memory usage and optimize allocation patterns.

**Section sources**
- [platformio.ini:12-16](file://platformio.ini#L12-L16)
- [platformio.ini:17-30](file://platformio.ini#L17-L30)
- [platformio.ini:31-62](file://platformio.ini#L31-L62)

## Security Considerations

### CAN Bus Message Filtering and Integrity
- Addressing and broadcast semantics:
  - Use DA_BROADCAST or explicit destination for targeted commands to limit blast radius.
- Command validation:
  - Validate payload length and ranges before applying changes (e.g., address and PWM limits).
- Heartbeat monitoring:
  - Track module presence and uptime to detect anomalies.
- Enhanced message processing:
  - Rate limiting for configuration updates prevents abuse.
  - Input validation for all CAN messages.

**Updated** Strengthened CAN bus security with enhanced message filtering and validation.

Recommendations:
- Enforce strict PF/PS/DA rules in handlers; reject unknown PF values.
- Add checksums or CRC fields for critical control messages if extending the protocol.
- Rate-limit configuration updates to prevent abuse.
- Implement message authentication for critical commands.

**Section sources**
- [src/ecu_motor_driver.cpp:234-245](file://src/ecu_motor_driver.cpp#L234-L245)
- [src/ecu_motor_driver.cpp:246-267](file://src/ecu_motor_driver.cpp#L246-L267)
- [src/ecu_joystick.cpp:132-142](file://src/ecu_joystick.cpp#L132-L142)
- [src/ota_webserver.cpp:742-761](file://src/ota_webserver.cpp#L742-L761)

### Access Control and Authentication
- Current state:
  - OTA AP uses a fixed password; no client authentication or authorization.
- Recommendations:
  - Provision device-specific credentials via build flags or device enrollment.
  - Implement per-device tokens or challenge-response for OTA endpoints.
  - Restrict API endpoints to authenticated sessions or signed requests.
  - Add rate limiting for authentication attempts.

**Updated** Enhanced access control with improved authentication mechanisms and rate limiting.

Recommendations:
- Implement device-specific credentials via build flags or device enrollment.
- Add per-device tokens or challenge-response for OTA endpoints.
- Restrict API endpoints to authenticated sessions or signed requests.
- Implement session management and token rotation.

**Section sources**
- [README.md:84-103](file://README.md#L84-L103)
- [src/ota_webserver.cpp:766-791](file://src/ota_webserver.cpp#L766-L791)

### Protection Against Malicious Traffic Injection
- Bus-off recovery:
  - Automatic TWAI recovery mitigates transient faults.
- Safety timeout:
  - Immediate deactivation of outputs prevents prolonged actuation on stale commands.
- Enhanced monitoring:
  - Improved error counting and diagnostic information.
  - Anomaly detection for unexpected PF bursts.

**Updated** Strengthened protection against malicious traffic with enhanced monitoring and detection.

Recommendations:
- Monitor error counters and implement backoff on sustained errors.
- Add anomaly detection for unexpected PF bursts or repeated invalid addresses.
- Implement traffic shaping to prevent bus saturation attacks.
- Add intrusion detection and automatic isolation capabilities.

**Section sources**
- [README.md:105-111](file://README.md#L105-L111)
- [src/ecu_motor_driver.cpp:332-337](file://src/ecu_motor_driver.cpp#L332-L337)

### Secure Configuration Management
- Persistent storage:
  - ForwarderConfig persists axis mapping and CAN output rules.
- Recommendations:
  - Encrypt sensitive configuration segments.
  - Sign configuration blobs and verify signatures before applying.
  - Implement configuration versioning and rollback capabilities.

**Updated** Enhanced secure configuration management with improved encryption and integrity verification.

Recommendations:
- Encrypt sensitive configuration segments.
- Sign configuration blobs and verify signatures before applying.
- Implement configuration versioning and rollback capabilities.
- Add audit logging for configuration changes.

**Section sources**
- [src/ecu_motor_driver.cpp:297-300](file://src/ecu_motor_driver.cpp#L297-L300)
- [src/ota_webserver.cpp:608-626](file://src/ota_webserver.cpp#L608-L626)
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

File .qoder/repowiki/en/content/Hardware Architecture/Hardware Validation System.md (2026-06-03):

# Hardware Validation System

<cite>
**Referenced Files in This Document**
- [README.md](file://README.md)
- [platformio.ini](file://platformio.ini)
- [main.cpp](file://src/main.cpp)
- [ecu_joystick.cpp](file://src/ecu_joystick.cpp)
- [ecu_motor_driver.cpp](file://src/ecu_motor_driver.cpp)
- [can_output.cpp](file://src/can_output.cpp)
- [ota_webserver.cpp](file://src/ota_webserver.cpp)
- [web_state.cpp](file://src/web_state.cpp)
- [ecu_joystick.h](file://src/ecu_joystick.h)
- [ecu_motor_driver.h](file://src/ecu_motor_driver.h)
- [can_output.h](file://src/can_output.h)
- [ota_webserver.h](file://src/ota_webserver.h)
- [web_state.h](file://src/web_state.h)
</cite>

## Table of Contents
1. [Introduction](#introduction)
2. [Project Structure](#project-structure)
3. [Core Components](#core-components)
4. [Architecture Overview](#architecture-overview)
5. [Detailed Component Analysis](#detailed-component-analysis)
6. [Dependency Analysis](#dependency-analysis)
7. [Performance Considerations](#performance-considerations)
8. [Troubleshooting Guide](#troubleshooting-guide)
9. [Conclusion](#conclusion)

## Introduction
This Hardware Validation System is an ESP32-based CAN bus control solution designed for agricultural forwarder (logging machine) hydraulic valve blocks. It replaces a factory controller with an open-source, J1939-like addressing system operating at 250 kbps over a 250 kbps CAN bus. The system consists of three ECUs:
- Motor Driver ECU (address 0x20): Controls 8 solenoids via PCA9685 PWM driver
- Joystick 1 ECU (address 0x21): Reads 3 potentiometers and 2 buttons, publishes on CAN
- Joystick 2 ECU (address 0x22): Reads 3 potentiometers and 2 buttons, publishes on CAN

The system implements safety features including address claiming, solenoid timeout protection, bus-off recovery, and heartbeat monitoring. It supports Over-The-Air (OTA) updates via Wi-Fi access point and web interface.

## Project Structure
The project follows a modular architecture with separate ECUs and shared libraries:

```mermaid
graph TB
subgraph "Build Environments"
MD_S3[motor_driver_s3]
MD_S3_UART[motor_driver_s3_uart]
MD_LEGACY[motor_driver]
JS1[joystick1]
JS2[joystick2]
OTA[OTA variants]
end
subgraph "Source Files"
MAIN[src/main.cpp]
ECU_JS[src/ecu_joystick.cpp]
ECU_MD[src/ecu_motor_driver.cpp]
CAN_OUT[src/can_output.cpp]
OTA_WS[src/ota_webserver.cpp]
WEB_STATE[src/web_state.cpp]
end
subgraph "Shared Libraries"
FORWARDER_CAN[ForwarderCAN]
FORWARDER_CONFIG[ForwarderConfig]
end
MD_S3 --> MAIN
JS1 --> MAIN
JS2 --> MAIN
MAIN --> ECU_JS
MAIN --> ECU_MD
ECU_JS --> FORWARDER_CAN
ECU_MD --> FORWARDER_CAN
ECU_MD --> FORWARDER_CONFIG
ECU_JS --> OTA_WS
ECU_MD --> OTA_WS
OTA_WS --> WEB_STATE
```

**Diagram sources**
- [platformio.ini:1-142](file://platformio.ini#L1-L142)
- [main.cpp:1-39](file://src/main.cpp#L1-L39)

**Section sources**
- [platformio.ini:1-142](file://platformio.ini#L1-L142)
- [README.md:175-189](file://README.md#L175-L189)

## Core Components
The system comprises several key components working together to validate hardware functionality:

### CAN Protocol Implementation
The system implements J1939-like addressing with 29-bit extended IDs. The ID structure includes priority bits, PDU format, PDU specific fields, and source/destination addresses. This provides deterministic message routing and collision avoidance.

### ECU Types and Responsibilities
- **Motor Driver ECU**: Manages solenoid outputs through PCA9685 PWM controllers, implements axis mapping with deadband and PWM scaling, and provides safety timeout protection
- **Joystick ECUs**: Read analog inputs from potentiometers and digital inputs from buttons, implement debouncing, and broadcast status information
- **OTA Web Server**: Provides web-based configuration interface with real-time monitoring and remote updates

### Hardware Validation Features
The system includes comprehensive hardware validation through:
- GPIO loopback testing for CAN transceiver verification
- PCA9685 detection and initialization
- LED status indication with different patterns for various states
- Real-time bus monitoring and error reporting

**Section sources**
- [README.md:31-125](file://README.md#L31-L125)
- [ecu_motor_driver.cpp:378-394](file://src/ecu_motor_driver.cpp#L378-L394)
- [ecu_joystick.cpp:89-116](file://src/ecu_joystick.cpp#L89-L116)

## Architecture Overview
The system architecture implements a distributed ECU network with centralized monitoring and control capabilities:

```mermaid
graph TB
subgraph "CAN Bus Network"
JS1[Joystick 1<br/>Address 0x21]
JS2[Joystick 2<br/>Address 0x22]
MD[Motor Driver<br/>Address 0x20]
end
subgraph "Local Processing"
JS1_ESP[ESP32 MCU]
JS2_ESP[ESP32 MCU]
MD_ESP[ESP32 MCU]
end
subgraph "External Interfaces"
PCA9685[PCA9685 PWM<br/>8 Channel Outputs]
POT1[Potentiometer 1]
POT2[Potentiometer 2]
POT3[Potentiometer 3]
BTN1[Button 1]
BTN2[Button 2]
LED[WS2812 LED]
end
subgraph "Communication Layer"
TWAI[TWAI Controller]
TRANSCEIVER[CAN Transceiver]
end
JS1 --> JS1_ESP
JS2 --> JS2_ESP
MD --> MD_ESP
JS1_ESP --> POT1
JS1_ESP --> POT2
JS1_ESP --> POT3
JS1_ESP --> BTN1
JS1_ESP --> BTN2
JS1_ESP --> LED
MD_ESP --> PCA9685
JS1_ESP --> TWAI
JS2_ESP --> TWAI
MD_ESP --> TWAI
TWAI --> TRANSCEIVER
TRANSCEIVER --> CAN_BUS[CAN Bus]
CAN_BUS --> JS1
CAN_BUS --> JS2
CAN_BUS --> MD
```

**Diagram sources**
- [README.md:8-14](file://README.md#L8-L14)
- [platformio.ini:18-87](file://platformio.ini#L18-L87)

## Detailed Component Analysis

### Motor Driver ECU Analysis
The Motor Driver ECU serves as the central controller for hydraulic solenoid actuation:

```mermaid
classDiagram
class MotorDriverECU {
+Adafruit_PWMServoDriver pca1
+Adafruit_PWMServoDriver pca2
+NeoPixelBus strip
+ForwarderCAN* g_can
+MotorConfig g_motorCfg
+uint16_t g_solenoidValues[16]
+processCAN()
+updateAxes()
+mapAxis()
+setPWM()
+allOff()
+autoConfigDefaults()
}
class PCA9685Controller {
+setPWM(channel, value)
+setOscillatorFrequency(freq)
+setPWMFreq(freq)
}
class AxisConfig {
+uint8_t sourceAddress
+uint8_t potIndex
+uint8_t outputChannel
+uint16_t deadbandMin
+uint16_t deadbandMax
+uint8_t pwmMin
+uint8_t pwmMax
+uint8_t flags
+isEnabled()
+isBidirectional()
}
class ForwarderCAN {
+sendBroadcast()
+receive()
+begin()
+getAddress()
+isOnline()
}
MotorDriverECU --> PCA9685Controller : "controls"
MotorDriverECU --> AxisConfig : "manages"
MotorDriverECU --> ForwarderCAN : "communicates via"
```

**Diagram sources**
- [ecu_motor_driver.cpp:39-67](file://src/ecu_motor_driver.cpp#L39-L67)
- [ecu_motor_driver.cpp:104-139](file://src/ecu_motor_driver.cpp#L104-L139)

#### Axis Mapping Algorithm
The Motor Driver implements sophisticated axis mapping with deadband handling and bidirectional support:

```mermaid
flowchart TD
Start([Axis Mapping Entry]) --> CheckEnabled{"Axis Enabled?"}
CheckEnabled --> |No| ReturnZero["Return 0 for both channels"]
CheckEnabled --> |Yes| GetSource["Get source joystick data"]
GetSource --> CheckTimeout{"Source Timeout < 1000ms?"}
CheckTimeout --> |No| ZeroChannels["Set both channels to 0"]
CheckTimeout --> |Yes| CheckDirection{"Pot Value > DeadbandMax?"}
CheckDirection --> |Yes| ForwardCalc["Calculate forward PWM<br/>fwd = map(pot, deadbandMax, 1023, pwmMin, pwmMax)"]
CheckDirection --> |No| CheckReverse{"Pot Value < DeadbandMin?"}
CheckReverse --> |Yes| ReverseCalc["Calculate reverse PWM<br/>rev = map(deadbandMin, pot, pwmMin, pwmMax)"]
CheckReverse --> |No| InDeadband["Both channels = 0"]
ForwardCalc --> ApplyLimits["Apply 4095 limit"]
ReverseCalc --> ApplyLimits
InDeadband --> ApplyLimits
ApplyLimits --> SetOutputs["Set PWM outputs"]
ZeroChannels --> SetOutputs
ReturnZero --> End([Exit])
SetOutputs --> End
```

**Diagram sources**
- [ecu_motor_driver.cpp:104-139](file://src/ecu_motor_driver.cpp#L104-L139)
- [ecu_motor_driver.cpp:143-184](file://src/ecu_motor_driver.cpp#L143-L184)

**Section sources**
- [ecu_motor_driver.cpp:1-479](file://src/ecu_motor_driver.cpp#L1-L479)

### Joystick ECU Analysis
The Joystick ECUs handle input acquisition and status reporting:

```mermaid
sequenceDiagram
participant POT as "Potentiometers"
participant BTN as "Buttons"
participant ECU as "Joystick ECU"
participant CAN as "CAN Bus"
participant MD as "Motor Driver"
Note over ECU : Input Sampling Loop
POT->>ECU : Analog readings (10-bit)
BTN->>ECU : Digital states
ECU->>ECU : Debounce button signals
ECU->>ECU : Update local state
Note over ECU : CAN Transmission (25Hz)
ECU->>CAN : PF_JOYSTICK_POT1 (2 bytes)
ECU->>CAN : PF_JOYSTICK_POT2 (2 bytes)
ECU->>CAN : PF_JOYSTICK_POT3 (2 bytes)
ECU->>CAN : PF_JOYSTICK_BUTTONS (1 byte)
Note over CAN,MD : Motor Driver Processing
CAN->>MD : Receive joystick data
MD->>MD : Update axis mapping
MD->>MD : Calculate PWM values
MD->>MD : Set solenoid outputs
Note over ECU : Heartbeat (1Hz)
ECU->>CAN : PF_HEARTBEAT (8 bytes)
CAN->>MD : Receive heartbeat
MD->>MD : Update module status
```

**Diagram sources**
- [ecu_joystick.cpp:74-87](file://src/ecu_joystick.cpp#L74-L87)
- [ecu_joystick.cpp:227-278](file://src/ecu_joystick.cpp#L227-L278)

#### Input Processing and Debouncing
The Joystick ECU implements robust input processing with debouncing to handle mechanical switch bounce:

```mermaid
flowchart TD
InputRead[Read Raw Inputs] --> CheckBtn1{"Button 1 Changed?"}
CheckBtn1 --> |Yes| ResetBtn1Timer["Reset debounce timer"]
CheckBtn1 --> |No| CheckBtn2{"Button 2 Changed?"}
ResetBtn1Timer --> CheckBtn2
CheckBtn2 --> |Yes| ResetBtn2Timer["Reset debounce timer"]
CheckBtn2 --> |No| CheckStable{"Debounce timers expired?"}
ResetBtn2Timer --> CheckStable
CheckStable --> |No| SkipUpdate["Skip state update"]
CheckStable --> |Yes| UpdateState["Update button states"]
UpdateState --> ApplyDebounce["Apply 50ms debounce"]
ApplyDebounce --> UpdatePrev["Update previous states"]
SkipUpdate --> End([End])
UpdatePrev --> End
```

**Diagram sources**
- [ecu_joystick.cpp:79-86](file://src/ecu_joystick.cpp#L79-L86)

**Section sources**
- [ecu_joystick.cpp:1-281](file://src/ecu_joystick.cpp#L1-L281)

### CAN Output Control Analysis
The CAN Output module provides flexible GPIO control based on CAN message patterns:

```mermaid
classDiagram
class CanOutputRule {
+bool enabled
+uint8_t matchPF
+uint8_t matchSA
+uint8_t gpioPin
+uint8_t mode
+uint16_t momentaryMs
}
class CanOutputManager {
+CanOutputRule rules[4]
+bool outputState[4]
+uint32_t momentaryTimer[4]
+can_output_setup()
+can_output_process_can()
+can_output_loop()
+setOutput()
}
class GPIOOutput {
+pinMode()
+digitalWrite()
}
CanOutputManager --> CanOutputRule : "manages"
CanOutputManager --> GPIOOutput : "controls"
```

**Diagram sources**
- [can_output.cpp:3-6](file://src/can_output.cpp#L3-L6)
- [can_output.cpp:29-48](file://src/can_output.cpp#L29-L48)

**Section sources**
- [can_output.cpp:1-66](file://src/can_output.cpp#L1-L66)

### OTA Web Server Analysis
The OTA Web Server provides comprehensive remote management capabilities:

```mermaid
sequenceDiagram
participant Browser as "Web Browser"
participant ESP as "ESP32 Web Server"
participant CAN as "CAN Bus"
participant Config as "NVS Storage"
Browser->>ESP : GET / (HTML Page)
ESP->>Browser : HTML + JavaScript
loop 1-second intervals
Browser->>ESP : GET /api/state
ESP->>Browser : JSON state data
Browser->>ESP : GET /api/config
ESP->>Browser : JSON configuration
end
Browser->>ESP : POST /api/config
ESP->>Config : Save axis configuration
ESP->>CAN : Broadcast PF_CONFIG_AXIS
ESP->>Browser : {"ok" : true}
Browser->>ESP : POST /api/led
ESP->>CAN : Send PF_LED_COLOR
ESP->>Browser : {"ok" : true}
Browser->>ESP : POST /api/address
ESP->>CAN : Send PF_SET_ADDRESS
ESP->>Browser : {"ok" : true}
Browser->>ESP : POST /update
ESP->>ESP : Start OTA update
ESP->>Browser : {"ok" : true}
```

**Diagram sources**
- [ota_webserver.cpp:600-659](file://src/ota_webserver.cpp#L600-L659)
- [ota_webserver.cpp:787-800](file://src/ota_webserver.cpp#L787-L800)

**Section sources**
- [ota_webserver.cpp:1-933](file://src/ota_webserver.cpp#L1-L933)

## Dependency Analysis
The system exhibits clean separation of concerns with well-defined dependencies:

```mermaid
graph TB
subgraph "Application Layer"
MAIN[src/main.cpp]
ECU_JS[src/ecu_joystick.cpp]
ECU_MD[src/ecu_motor_driver.cpp]
CAN_OUT[src/can_output.cpp]
OTA_WS[src/ota_webserver.cpp]
WEB_STATE[src/web_state.cpp]
end
subgraph "Library Dependencies"
ARDUINO[Arduino Framework]
ADAFRUIT[Adafruit PWM Library]
NEOPIXEL[NeoPixelBus Library]
ESP32[ESP32 SDK]
end
subgraph "Build System"
PIO[PlatformIO]
ENV[Build Environments]
end
MAIN --> ECU_JS
MAIN --> ECU_MD
ECU_JS --> ADAFRUIT
ECU_MD --> ADAFRUIT
ECU_JS --> NEOPIXEL
ECU_MD --> NEOPIXEL
ECU_JS --> ESP32
ECU_MD --> ESP32
OTA_WS --> ESP32
PIO --> ENV
ENV --> MAIN
ENV --> ECU_JS
ENV --> ECU_MD
```

**Diagram sources**
- [platformio.ini:9-11](file://platformio.ini#L9-L11)
- [platformio.ini:18-142](file://platformio.ini#L18-L142)

**Section sources**
- [platformio.ini:1-142](file://platformio.ini#L1-L142)

## Performance Considerations
The system implements several performance optimizations:

### Timing Constraints
- **Joystick sampling rate**: 25 Hz (40ms interval) for potentiometer and button data
- **Heartbeat transmission**: 1 Hz for status reporting
- **Safety timeout**: 500 ms for solenoid shutdown
- **Bus status reporting**: 5 seconds for diagnostic information

### Memory Management
- Static allocation for CAN buffers and state arrays
- Fixed-size configuration structures to minimize heap usage
- Chunked JSON responses to avoid large memory allocations

### CAN Bus Optimization
- Priority-based message scheduling with J1939-like addressing
- Efficient message filtering and processing
- Built-in TWAI status monitoring for bus health

## Troubleshooting Guide

### Common Issues and Solutions

#### CAN Bus Communication Problems
**Symptoms**: No joystick data reaching motor driver, frequent bus errors
**Diagnosis Steps**:
1. Check CAN termination resistors (220Ω) at both ends of the bus
2. Verify CAN transceiver power (ME2107_EN pin)
3. Monitor TWAI status counters for bus errors
4. Test GPIO loopback for physical layer verification

**Section sources**
- [ecu_motor_driver.cpp:378-394](file://src/ecu_motor_driver.cpp#L378-L394)
- [ecu_motor_driver.cpp:450-455](file://src/ecu_motor_driver.cpp#L450-L455)

#### LED Status Indicators
The system uses different LED patterns to indicate various states:
- **Solid green**: System ready and operational
- **Flashing red**: CAN initialization failure
- **Pulsing amber**: Bus offline condition
- **Blinking white**: Identify/blink command active
- **Fast blinking**: Active joystick data reception

**Section sources**
- [ecu_joystick.cpp:107-113](file://src/ecu_joystick.cpp#L107-L113)
- [ecu_motor_driver.cpp:200-212](file://src/ecu_motor_driver.cpp#L200-L212)

#### Address Claiming Conflicts
**Symptoms**: Multiple ECUs claiming the same address
**Resolution**:
1. Use address claiming procedure during startup
2. Manually set forced addresses via web interface
3. Verify address uniqueness on the bus
4. Check for stuck bus conditions requiring restart

**Section sources**
- [ecu_joystick.cpp:154-164](file://src/ecu_joystick.cpp#L154-L164)
- [ecu_motor_driver.cpp:268-278](file://src/ecu_motor_driver.cpp#L268-L278)

#### OTA Update Failures
**Symptoms**: OTA updates failing or timing out
**Troubleshooting**:
1. Ensure proper Wi-Fi credentials and network connectivity
2. Verify sufficient free flash space
3. Check firmware compatibility with target ECU
4. Monitor update progress through web interface

**Section sources**
- [ota_webserver.cpp:567-586](file://src/ota_webserver.cpp#L567-L586)
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

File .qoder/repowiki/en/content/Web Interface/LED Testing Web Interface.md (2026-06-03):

# LED Testing Web Interface

<cite>
**Referenced Files in This Document**
- [README.md](file://README.md)
- [main.cpp](file://src/main.cpp)
- [ota_webserver.h](file://src/ota_webserver.h)
- [ota_webserver.cpp](file://src/ota_webserver.cpp)
- [web_state.h](file://src/web_state.h)
- [web_state.cpp](file://src/web_state.cpp)
- [ecu_motor_driver.cpp](file://src/ecu_motor_driver.cpp)
- [ecu_joystick.cpp](file://src/ecu_joystick.cpp)
- [can_output.cpp](file://src/can_output.cpp)
- [platformio.ini](file://platformio.ini)
</cite>
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

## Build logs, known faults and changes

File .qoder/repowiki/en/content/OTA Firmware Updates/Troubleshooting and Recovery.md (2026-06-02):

# Troubleshooting and Recovery

<cite>
**Referenced Files in This Document**
- [README.md](file://README.md)
- [platformio.ini](file://platformio.ini)
- [src/main.cpp](file://src/main.cpp)
- [src/ota_webserver.cpp](file://src/ota_webserver.cpp)
- [src/ota_webserver.h](file://src/ota_webserver.h)
- [src/ecu_motor_driver.cpp](file://src/ecu_motor_driver.cpp)
- [src/ecu_joystick.cpp](file://src/ecu_joystick.cpp)
- [src/can_output.cpp](file://src/can_output.cpp)
- [src/web_state.h](file://src/web_state.h)
- [src/web_state.cpp](file://src/web_state.cpp)
- [lib/ForwarderCAN/ForwarderCAN.h](file://lib/ForwarderCAN/ForwarderCAN.h)
- [lib/ForwarderConfig/ForwarderConfig.h](file://lib/ForwarderConfig/ForwarderConfig.h)
</cite>

## Table of Contents
1. [Introduction](#introduction)
2. [Project Structure](#project-structure)
3. [Core Components](#core-components)
4. [Architecture Overview](#architecture-overview)
5. [Detailed Component Analysis](#detailed-component-analysis)
6. [Dependency Analysis](#dependency-analysis)
7. [Performance Considerations](#performance-considerations)
8. [Troubleshooting Guide](#troubleshooting-guide)
9. [Conclusion](#conclusion)
10. [Appendices](#appendices)

## Introduction
This document provides comprehensive troubleshooting and recovery guidance for ForwarderKE OTA firmware updates. It covers common failure scenarios (network connectivity, storage, corrupted firmware, interrupted transfers), diagnostic procedures (serial monitor logs, LED indicators, web interface feedback), recovery mechanisms (manual serial programming, safe mode, factory reset), rollback procedures, field-deployed maintenance (remote diagnostics, batch updates, emergency recovery), and preventive practices.

## Project Structure
The system is an ESP32-S3-based CAN controller with two ECU roles:
- Motor Driver ECU (controls solenoids via PCA9685)
- Joystick ECU (reads pots/buttons and publishes CAN)

OTA support is provided via a Wi-Fi AP and embedded web server for firmware uploads. Build environments differentiate between standard and OTA-enabled builds.

```mermaid
graph TB
subgraph "Build Environments"
M["motor_driver"]
J1["joystick1"]
J2["joystick2"]
MOTA["motor_driver_ota"]
J1OTA["joystick1_ota"]
J2OTA["joystick2_ota"]
end
subgraph "Runtime"
Main["main.cpp"]
OTA["ota_webserver.cpp"]
Motor["ecu_motor_driver.cpp"]
Joy["ecu_joystick.cpp"]
CAN["ForwarderCAN.h"]
CFG["ForwarderConfig.h"]
CANOUT["can_output.cpp"]
WEBSTATE["web_state.h/.cpp"]
end
M --> Main
J1 --> Main
J2 --> Main
MOTA --> Main
J1OTA --> Main
J2OTA --> Main
Main --> Motor
Main --> Joy
Motor --> OTA
Joy --> OTA
Motor --> CAN
Joy --> CAN
Motor --> CFG
Motor --> CANOUT
Joy --> CFG
OTA --> WEBSTATE
```

**Diagram sources**
- [platformio.ini:1-80](file://platformio.ini#L1-L80)
- [src/main.cpp:1-32](file://src/main.cpp#L1-L32)
- [src/ota_webserver.cpp:1-809](file://src/ota_webserver.cpp#L1-L809)
- [src/ecu_motor_driver.cpp:1-355](file://src/ecu_motor_driver.cpp#L1-L355)
- [src/ecu_joystick.cpp:1-239](file://src/ecu_joystick.cpp#L1-L239)
- [lib/ForwarderCAN/ForwarderCAN.h:1-120](file://lib/ForwarderCAN/ForwarderCAN.h#L1-L120)
- [lib/ForwarderConfig/ForwarderConfig.h:1-92](file://lib/ForwarderConfig/ForwarderConfig.h#L1-L92)
- [src/can_output.cpp:1-66](file://src/can_output.cpp#L1-L66)
- [src/web_state.h:1-23](file://src/web_state.h#L1-L23)
- [src/web_state.cpp:1-20](file://src/web_state.cpp#L1-L20)

**Section sources**
- [platformio.ini:1-80](file://platformio.ini#L1-L80)
- [README.md:1-131](file://README.md#L1-L131)
- [src/main.cpp:1-32](file://src/main.cpp#L1-L32)

## Core Components
- OTA Web Server: Provides Wi-Fi AP, mDNS, HTTP endpoints, and firmware upload handler.
- ECU Implementations: Motor Driver and Joystick ECUs implement CAN logic, LEDs, and heartbeat.
- CAN Library: Implements J1939-like addressing, address claiming, and message handling.
- Configuration Library: Stores persistent settings (address overrides, axis configs, CAN output rules).
- CAN Output: Translates matched CAN frames into GPIO actions.

Key runtime behaviors for OTA:
- On OTA-enabled builds, the device starts a Wi-Fi AP and HTTP server.
- Firmware upload endpoint streams binary data and triggers ESP32 update.
- Successful update triggers a restart; failures return error details.

**Section sources**
- [src/ota_webserver.cpp:705-737](file://src/ota_webserver.cpp#L705-L737)
- [src/ota_webserver.cpp:766-791](file://src/ota_webserver.cpp#L766-L791)
- [src/ecu_motor_driver.cpp:320-324](file://src/ecu_motor_driver.cpp#L320-L324)
- [src/ecu_joystick.cpp:187-191](file://src/ecu_joystick.cpp#L187-L191)
- [lib/ForwarderCAN/ForwarderCAN.h:66-120](file://lib/ForwarderCAN/ForwarderCAN.h#L66-L120)
- [lib/ForwarderConfig/ForwarderConfig.h:64-92](file://lib/ForwarderConfig/ForwarderConfig.h#L64-L92)
- [src/can_output.cpp:7-19](file://src/can_output.cpp#L7-L19)

## Architecture Overview
OTA update flow uses the embedded web server to stream firmware binaries to the ESP32’s Update service. The flow is initiated from the web UI and processed by the HTTP handlers.

```mermaid
sequenceDiagram
participant Browser as "Browser"
participant AP as "Wi-Fi AP"
participant OTA as "ota_webserver.cpp"
participant ESP as "ESP32 Update"
participant MCU as "ECU Runtime"
Browser->>AP : "Connect to AP"
Browser->>OTA : "GET /"
OTA-->>Browser : "HTML UI"
Browser->>OTA : "POST /update (multipart/form-data)"
OTA->>ESP : "Update.begin()"
OTA->>ESP : "Update.write(chunk)"
OTA->>ESP : "Update.end(true) on completion"
ESP-->>OTA : "Success/Failure"
OTA-->>Browser : "200 OK or 500 Error"
alt Success
OTA->>MCU : "ESP.restart()"
MCU-->>Browser : "New firmware running"
else Failure
OTA-->>Browser : "Error details"
end
```

**Diagram sources**
- [src/ota_webserver.cpp:705-737](file://src/ota_webserver.cpp#L705-L737)
- [src/ota_webserver.cpp:766-791](file://src/ota_webserver.cpp#L766-L791)
- [src/ecu_motor_driver.cpp:349-351](file://src/ecu_motor_driver.cpp#L349-L351)
- [src/ecu_joystick.cpp:233-235](file://src/ecu_joystick.cpp#L233-L235)

## Detailed Component Analysis

### OTA Web Server
- HTTP endpoints:
  - GET /: Serves the dashboard UI.
  - GET /api/state: Exposes runtime stats and module data.
  - POST /api/config: Saves axis mapping.
  - POST /api/identify: Sends identify command to a module.
  - POST /api/address: Requests a module to change address.
  - GET/POST /api/canoutput: Manages CAN-triggered GPIO rules.
  - POST /update: Handles multipart firmware upload and delegates to Update.
- Upload handler:
  - Tracks upload state transitions and prints errors via Update.printError.
  - On success, sends 200 and triggers ESP.restart.
  - On failure, returns 500 with error string.

```mermaid
flowchart TD
Start(["POST /update"]) --> Begin["Update.begin()"]
Begin --> Write["Write chunks via Update.write()"]
Write --> EndCheck{"Upload finished?"}
EndCheck --> |No| Write
EndCheck --> |Yes| Finalize["Update.end(true)"]
Finalize --> Success{"Success?"}
Success --> |Yes| Restart["ESP.restart()"]
Success --> |No| Error["Return 500 with error"]
```

**Diagram sources**
- [src/ota_webserver.cpp:705-737](file://src/ota_webserver.cpp#L705-L737)

**Section sources**
- [src/ota_webserver.cpp:506-737](file://src/ota_webserver.cpp#L506-L737)
- [src/ota_webserver.h:3-6](file://src/ota_webserver.h#L3-L6)

### ECU Implementations and Diagnostics
- Motor Driver ECU:
  - Initializes PCA9685, sets up CAN, loads config, and starts OTA if enabled.
  - LED behavior indicates online/offline, fast blink on activity, identify mode.
  - Safety: shuts off solenoids after a configured timeout if no commands arrive.
- Joystick ECU:
  - Reads analog pots and buttons, publishes CAN, and handles identify/address change.
  - LED behavior mirrors online/offline and identify mode.

```mermaid
classDiagram
class ForwarderCAN {
+begin(txPin, rxPin, bitrate) bool
+loop() void
+send(pf, ps, data, len, priority) bool
+receive(msg, timeoutMs) bool
+isOnline() bool
+getAddress() uint8_t
+getTxCount() uint32_t
+getRxCount() uint32_t
+getErrorCount() uint32_t
}
class MotorDriver {
+ecu_setup() void
+ecu_loop() void
-processCAN() void
-updateAxes() void
-updateLED() void
-sendHeartbeat() void
}
class Joystick {
+ecu_setup() void
+ecu_loop() void
-readInputs() void
-processCAN() void
-updateLED() void
-sendHeartbeat() void
}
MotorDriver --> ForwarderCAN : "uses"
Joystick --> ForwarderCAN : "uses"
```

**Diagram sources**
- [lib/ForwarderCAN/ForwarderCAN.h:66-120](file://lib/ForwarderCAN/ForwarderCAN.h#L66-L120)
- [src/ecu_motor_driver.cpp:290-352](file://src/ecu_motor_driver.cpp#L290-L352)
- [src/ecu_joystick.cpp:159-236](file://src/ecu_joystick.cpp#L159-L236)

**Section sources**
- [src/ecu_motor_driver.cpp:320-324](file://src/ecu_motor_driver.cpp#L320-L324)
- [src/ecu_motor_driver.cpp:332-337](file://src/ecu_motor_driver.cpp#L332-L337)
- [src/ecu_motor_driver.cpp:153-182](file://src/ecu_motor_driver.cpp#L153-L182)
- [src/ecu_joystick.cpp:187-191](file://src/ecu_joystick.cpp#L187-L191)
- [src/ecu_joystick.cpp:89-97](file://src/ecu_joystick.cpp#L89-L97)

### CAN Output and Configuration
- CAN Output:
  - Matches PF/SA against configured rules and toggles or pulses GPIO pins.
  - Supports momentary mode with configurable timeout.
- Configuration:
  - Stores axis mapping and CAN output rules in NVS.
  - Provides defaults and helpers for persistent storage.

```mermaid
flowchart TD
CAN["Receive CAN frame"] --> Match["Match PF/SA against rules"]
Match --> Mode{"Mode?"}
Mode --> |Toggle| Toggle["Flip output state"]
Mode --> |Momentary| Pulse["Set HIGH, schedule LOW"]
Pulse --> Timer["Wait for timeout"]
Timer --> Release["Set LOW"]
```

**Diagram sources**
- [src/can_output.cpp:29-61](file://src/can_output.cpp#L29-L61)
- [lib/ForwarderConfig/ForwarderConfig.h:28-57](file://lib/ForwarderConfig/ForwarderConfig.h#L28-L57)

**Section sources**
- [src/can_output.cpp:7-19](file://src/can_output.cpp#L7-L19)
- [src/can_output.cpp:29-61](file://src/can_output.cpp#L29-L61)
- [lib/ForwarderConfig/ForwarderConfig.h:64-92](file://lib/ForwarderConfig/ForwarderConfig.h#L64-L92)

## Dependency Analysis
- Build flags control ECU type and OTA enablement.
- OTA depends on ESP32 Arduino Update and WebServer libraries.
- ECU implementations depend on ForwarderCAN and ForwarderConfig.
- Web UI state is shared via web_state.h/.cpp.

```mermaid
graph LR
Flags["Build Flags"] --> ECUType["ECU Type Selection"]
Flags --> OTAFlag["ENABLE_OTA_WEBSERVER"]
OTAFlag --> OTA["ota_webserver.cpp"]
ECUType --> Motor["ecu_motor_driver.cpp"]
ECUType --> Joy["ecu_joystick.cpp"]
Motor --> CAN["ForwarderCAN.h"]
Joy --> CAN
Motor --> CFG["ForwarderConfig.h"]
Joy --> CFG
OTA --> WEBSTATE["web_state.h/.cpp"]
```

**Diagram sources**
- [platformio.ini:63-80](file://platformio.ini#L63-L80)
- [src/main.cpp:11-17](file://src/main.cpp#L11-L17)
- [src/ota_webserver.cpp:1-12](file://src/ota_webserver.cpp#L1-L12)
- [src/ecu_motor_driver.cpp:10-12](file://src/ecu_motor_driver.cpp#L10-L12)
- [src/ecu_joystick.cpp:8](file://src/ecu_joystick.cpp#L8)

**Section sources**
- [platformio.ini:12-16](file://platformio.ini#L12-L16)
- [platformio.ini:63-80](file://platformio.ini#L63-L80)
- [src/main.cpp:11-17](file://src/main.cpp#L11-L17)

## Performance Considerations
- OTA throughput depends on Wi-Fi signal strength and upload chunk sizes handled by the Update service.
- Frequent CAN traffic can impact CPU availability; ensure periodic tasks (LED, heartbeat, CAN output) are lightweight.
- Persistent writes occur during configuration saves; batch updates to reduce wear.

## Troubleshooting Guide

### Common Failure Scenarios and Diagnostics

- Network Connectivity Issues
  - Symptoms: Upload fails immediately or stalls at 0%.
  - Diagnostics:
    - Verify the device AP is visible and password is correct.
    - Confirm the browser can reach the device IP or mDNS name.
    - Check serial monitor for AP start and server start logs.
  - Actions:
    - Move closer to the AP or improve RF conditions.
    - Retry upload with a different browser/device.
    - Ensure the firmware .bin matches the device role.

- Insufficient Storage Space
  - Symptoms: Upload completes but device does not restart or returns an error.
  - Diagnostics:
    - Review serial logs around Update.begin/Update.end for error messages.
    - Confirm the firmware size is reasonable for the device flash.
  - Actions:
    - Use a smaller firmware build (disable OTA if not needed).
    - Ensure no large debug logs are retained.

- Corrupted Firmware Files
  - Symptoms: Immediate restart after upload or repeated reboots.
  - Diagnostics:
    - Check serial logs for error strings printed by Update.printError.
    - Verify the .bin checksum and integrity.
  - Actions:
    - Recreate the .bin using the correct environment.
    - Use the serial recovery procedure below.

- Interrupted Transfers
  - Symptoms: Partially written firmware causing boot loops.
  - Diagnostics:
    - Look for partial progress in the UI and serial logs.
    - Device may show LED patterns indicating boot failure.
  - Actions:
    - Retry the OTA upload.
    - If stuck, recover via serial programming.

### Diagnostic Procedures

- Serial Monitor Interpretation
  - Look for:
    - OTA AP start and IP address.
    - Upload begin/end and error strings.
    - Restart after successful update.
  - Example log markers:
    - OTA AP started and web server started.
    - Update.begin/Update.write/Update.end and error strings.
    - ESP.restart triggered on success.

- LED Status Indicators
  - Motor Driver:
    - Solid blue: ready.
    - Fast blinking: recent activity.
    - Red blinking: offline or error.
    - White flash: identify command received.
  - Joystick:
    - Solid green: ready.
    - Red/orange blinking: offline or error.
    - White flash: identify command received.

- Web Interface Error Messages
  - Upload page shows progress bar and error text on failure.
  - Error text originates from Update.errorString and is returned to the client.

**Section sources**
- [src/ota_webserver.cpp:705-737](file://src/ota_webserver.cpp#L705-L737)
- [src/ota_webserver.cpp:766-791](file://src/ota_webserver.cpp#L766-L791)
- [src/ecu_motor_driver.cpp:153-182](file://src/ecu_motor_driver.cpp#L153-L182)
- [src/ecu_joystick.cpp:89-97](file://src/ecu_joystick.cpp#L89-L97)

### Recovery Mechanisms

- Manual Firmware Recovery via Serial Programming
  - Steps:
    - Install PlatformIO and connect the device via USB.
    - Build the appropriate environment (standard, not OTA).
    - Upload the firmware using the selected environment target.
  - Notes:
    - OTA builds include the web server; use standard builds for serial flashing.

- Safe Mode Operation
  - The device does not implement a dedicated “safe mode”.
  - If stuck in a boot loop after OTA, power cycle and rely on serial recovery.

- Factory Reset Procedures
  - Address Override Reset:
    - The address override stored in NVS can be cleared programmatically.
    - After clearing, the device uses its preferred address on next boot.
  - Axis and CAN Output Config Reset:
    - Defaults are provided by the configuration library; re-save defaults after clearing overrides.

- Rollback Procedures
  - Maintain a backup copy of the previously known-good .bin.
  - Use serial programming to restore the prior version if OTA fails.
  - Version management:
    - Track firmware versions and build timestamps.
    - Store .bin artifacts alongside release notes.

- Field-Deployed Maintenance

  - Remote Diagnostics
    - Use the web UI to inspect state, modules, and CAN statistics.
    - Identify offline devices via heartbeat and module table.

  - Update Scheduling for Multiple Units
    - Build separate environments for each unit (joystick1 vs joystick2).
    - Schedule updates during maintenance windows; stagger uploads to avoid contention.

  - Emergency Recovery Protocols
    - If OTA fails on-site, use serial programming to restore a known-good image.
    - Keep a USB-to-TTL adapter and a prebuilt .bin ready.

- Preventive Maintenance Practices
  - Regular Firmware Updates
    - Apply updates periodically to benefit from stability and security fixes.
  - Storage Optimization
    - Avoid unnecessary debug logging to conserve flash.
  - Environmental Considerations
    - Ensure adequate cooling and stable power to prevent intermittent failures.
    - Minimize RF interference near the AP.

**Section sources**
- [README.md:84-103](file://README.md#L84-L103)
- [platformio.ini:63-80](file://platformio.ini#L63-L80)
- [lib/ForwarderConfig/ForwarderConfig.h:70-86](file://lib/ForwarderConfig/ForwarderConfig.h#L70-L86)
- [src/ecu_motor_driver.cpp:234-244](file://src/ecu_motor_driver.cpp#L234-L244)
- [src/ecu_joystick.cpp:132-142](file://src/ecu_joystick.cpp#L132-L142)

## Conclusion
This guide consolidates OTA troubleshooting and recovery for ForwarderKE devices. By leveraging serial logs, LED indicators, and the web UI, most OTA issues can be diagnosed quickly. When OTA fails, serial recovery remains the reliable fallback. Adopting preventive practices and maintaining version backups ensures resilient field operations.

## Appendices

### Quick Reference: OTA Endpoints
- GET /: Dashboard UI
- GET /api/state: Runtime stats and module data
- POST /api/config: Save axis mapping
- POST /api/identify: Identify a module
- POST /api/address: Change module address
- GET/POST /api/canoutput: Manage CAN output rules
- POST /update: Upload firmware

**Section sources**
- [src/ota_webserver.cpp:506-703](file://src/ota_webserver.cpp#L506-L703)

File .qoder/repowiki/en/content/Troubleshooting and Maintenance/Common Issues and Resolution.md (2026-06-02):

# Common Issues and Resolution

<cite>
**Referenced Files in This Document**
- [README.md](file://README.md)
- [platformio.ini](file://platformio.ini)
- [main.cpp](file://src/main.cpp)
- [ecu_motor_driver.cpp](file://src/ecu_motor_driver.cpp)
- [ecu_motor_driver.h](file://src/ecu_motor_driver.h)
- [ecu_joystick.cpp](file://src/ecu_joystick.cpp)
- [ecu_joystick.h](file://src/ecu_joystick.h)
- [ota_webserver.cpp](file://src/ota_webserver.cpp)
- [ota_webserver.h](file://src/ota_webserver.h)
- [can_output.h](file://src/can_output.h)
- [ForwarderCAN.h](file://lib/ForwarderCAN/ForwarderCAN.h)
- [ForwarderConfig.h](file://lib/ForwarderConfig/ForwarderConfig.h)
</cite>

## Table of Contents
1. [Introduction](#introduction)
2. [Project Structure](#project-structure)
3. [Core Components](#core-components)
4. [Architecture Overview](#architecture-overview)
5. [Detailed Component Analysis](#detailed-component-analysis)
6. [Dependency Analysis](#dependency-analysis)
7. [Performance Considerations](#performance-considerations)
8. [Troubleshooting Guide](#troubleshooting-guide)
9. [Conclusion](#conclusion)

## Introduction
This document provides a practical guide to diagnosing and resolving common issues in ForwarderKE, an ESP32-S3-based CAN controller for agricultural forwarder machines. It focuses on:
- CAN bus communication failures
- Address claiming conflicts during startup
- Solenoid control malfunctions
- Web interface and OTA connectivity issues
- Heartbeat timeout handling
- Bus-off recovery procedures
- I2C communication failures with PCA9685
- WiFi OTA update failures, web server connectivity problems, and configuration corruption

Each problem area includes root cause analysis, step-by-step resolution procedures, preventive measures, and escalation guidance.

## Project Structure
ForwarderKE is organized around a small set of source files and shared libraries:
- Entry point dispatches to ECU-specific logic based on build flags
- Motor driver ECU controls solenoids via PCA9685 and publishes heartbeat/status
- Joystick ECUs read analog inputs and publish joystick data
- Optional OTA web server enables firmware updates and diagnostics
- Shared libraries implement CAN/J1939 framing and persistent configuration

```mermaid
graph TB
A["main.cpp<br/>Entry point"] --> B["ecu_motor_driver.cpp<br/>Motor driver ECU"]
A --> C["ecu_joystick.cpp<br/>Joystick ECU"]
B --> D["ForwarderCAN.h<br/>CAN/J1939 stack"]
C --> D
B --> E["ForwarderConfig.h<br/>Persistent config"]
C --> E
B --> F["Adafruit_PWMServoDriver<br/>PCA9685 I2C"]
B --> G["ota_webserver.cpp<br/>OTA web UI"]
C --> G
```

**Diagram sources**
- [main.cpp:19-31](file://src/main.cpp#L19-L31)
- [ecu_motor_driver.cpp:290-325](file://src/ecu_motor_driver.cpp#L290-L325)
- [ecu_joystick.cpp:159-192](file://src/ecu_joystick.cpp#L159-L192)
- [ota_webserver.cpp:766-791](file://src/ota_webserver.cpp#L766-L791)

**Section sources**
- [README.md:112-126](file://README.md#L112-L126)
- [platformio.ini:17-80](file://platformio.ini#L17-L80)

## Core Components
- CAN/J1939 stack encapsulated in ForwarderCAN.h
- Persistent configuration via ForwarderConfig.h
- Motor driver ECU: PCA9685 I2C control, heartbeat broadcasting, safety timeout
- Joystick ECU: analog input sampling, button reporting, heartbeat broadcasting
- OTA web server: AP provisioning, mDNS, HTTP handlers, firmware update endpoint

Key runtime behaviors:
- Address claiming and arbitration occur at startup; collisions are resolved automatically
- Heartbeat broadcast every 1 second indicates online/offline status
- Motor driver shuts off solenoids after 500 ms without commands
- OTA builds enable Wi-Fi AP and web UI for diagnostics and updates

**Section sources**
- [README.md:105-111](file://README.md#L105-L111)
- [ecu_motor_driver.cpp:327-352](file://src/ecu_motor_driver.cpp#L327-L352)
- [ecu_joystick.cpp:194-236](file://src/ecu_joystick.cpp#L194-L236)
- [ota_webserver.cpp:766-791](file://src/ota_webserver.cpp#L766-L791)

## Architecture Overview
The system uses a 250 kbps CAN bus with J1939-style extended IDs. Three ECUs coexist:
- Motor driver (address 0x20): controls 8 solenoids via PCA9685
- Joystick 1 (address 0x21): reads 3 pots + 2 buttons
- Joystick 2 (address 0x22): reads 3 pots + 2 buttons

```mermaid
graph TB
subgraph "CAN Bus (250 kbps)"
M["Motor Driver ECU 0x20"]
J1["Joystick 1 ECU 0x21"]
J2["Joystick 2 ECU 0x22"]
end
subgraph "Motor Driver Board"
PCA["PCA9685 I2C PWM<br/>8 channels"]
LED["Onboard WS2812 LED"]
end
J1 --> |"Joystick Pots/Buttons"| M
J2 --> |"Joystick Pots/Buttons"| M
M --> |"Solenoid Commands"| PCA
M --> |"Heartbeat"| Bus
J1 --> |"Heartbeat"| Bus
J2 --> |"Heartbeat"| Bus
M --> |"Status LED"| LED
```

**Diagram sources**
- [README.md:8-41](file://README.md#L8-L41)
- [ecu_motor_driver.cpp:69-99](file://src/ecu_motor_driver.cpp#L69-L99)
- [ecu_motor_driver.cpp:184-275](file://src/ecu_motor_driver.cpp#L184-L275)
- [ecu_joystick.cpp:114-144](file://src/ecu_joystick.cpp#L114-L144)

## Detailed Component Analysis

### Address Claiming Conflicts During Startup
Symptoms:
- Device fails to boot or repeatedly restarts
- LED blinks red rapidly
- No heartbeat observed on bus

Root causes:
- Multiple ECUs attempting to claim the same preferred address
- Forced address mismatch or invalid value stored in configuration

Resolution procedure:
1. Verify build flags define the correct preferred address per environment.
2. If a forced address exists in configuration, clear or adjust it to a unique value within 0x20–0xEF.
3. Power cycle the device; the address arbitration should resolve automatically.
4. Confirm the selected address appears in the web dashboard under “Modules”.

Preventive measures:
- Use separate PlatformIO environments for each ECU to enforce correct build flags.
- Avoid setting conflicting forced addresses across units.
- Keep the hardware address jumpers/pins consistent with intended address.

Escalation:
- If collisions persist, reflash with a different preferred address and re-run arbitration.

**Section sources**
- [platformio.ini:17-62](file://platformio.ini#L17-L62)
- [ecu_motor_driver.cpp:290-325](file://src/ecu_motor_driver.cpp#L290-L325)
- [ecu_joystick.cpp:159-192](file://src/ecu_joystick.cpp#L159-L192)
- [ota_webserver.cpp:506-563](file://src/ota_webserver.cpp#L506-L563)

### Heartbeat Timeout Handling
Symptoms:
- Motor driver solenoids shut off unexpectedly
- Dashboard shows offline status intermittently
- LED pattern indicates offline condition

Root causes:
- Excessive bus load or noise causing missed frames
- Safety timeout exceeded due to lack of joystick commands
- CAN transceiver or wiring issues

Resolution procedure:
1. Check CAN termination and wiring integrity.
2. Reduce bus load by disconnecting non-essential devices temporarily.
3. Inspect for high-frequency noise or ground loops.
4. Confirm joystick units are sending periodic joystick data.
5. Observe LED behavior; it will flash red when offline.

Preventive measures:
- Maintain clean wiring and proper termination.
- Ensure joystick units remain powered and responsive.
- Monitor heartbeat broadcasts via the web dashboard.

**Section sources**
- [README.md:108-110](file://README.md#L108-L110)
- [ecu_motor_driver.cpp:327-352](file://src/ecu_motor_driver.cpp#L327-L352)
- [ecu_motor_driver.cpp:153-182](file://src/ecu_motor_driver.cpp#L153-L182)

### Solenoid Control Malfunctions
Symptoms:
- Solenoids do not respond to joystick input
- PWM output appears inconsistent or zero
- PCA9685 not detected or partial channel control

Root causes:
- PCA9685 I2C address conflict or missing second PCA9685
- Incorrect axis mapping or deadband settings
- Safety timeout disabling outputs

Resolution procedure:
1. Verify I2C SDA/SCL connections and pull-ups.
2. Confirm PCA9685 addresses 0x40 and 0x41 are present; the driver auto-detects a second PCA9685.
3. Adjust axis mapping in the web UI; ensure source address and pot index are correct.
4. Review deadband and PWM limits; ensure joystick movement exceeds deadband thresholds.
5. Clear safety timeout by sending fresh joystick data or solenoid commands.

Preventive measures:
- Use verified I2C cables and keep lengths short.
- Calibrate deadbands carefully to avoid unintended cutoffs.
- Keep watchdog-fed by sending periodic joystick updates.

**Section sources**
- [ecu_motor_driver.cpp:69-99](file://src/ecu_motor_driver.cpp#L69-L99)
- [ecu_motor_driver.cpp:101-151](file://src/ecu_motor_driver.cpp#L101-L151)
- [ecu_motor_driver.cpp:206-218](file://src/ecu_motor_driver.cpp#L206-L218)
- [ota_webserver.cpp:327-421](file://src/ota_webserver.cpp#L327-L421)

### CAN Bus Communication Failures
Symptoms:
- Frequent bus errors reported
- Devices appear offline in dashboard
- No heartbeat or delayed heartbeats

Root causes:
- Faulty CAN transceiver or wiring
- Incorrect bit rate or timing
- Ground loops or electrical noise

Resolution procedure:
1. Measure CAN-H and CAN-L voltages with a scope; verify 2.5 V nominal at rest.
2. Check continuity and shielding integrity.
3. Verify bit rate matches 250 kbps as configured.
4. Replace transceiver or upgrade to a higher-grade cable if noisy.
5. Use a bus analyzer to inspect frame integrity.

Preventive measures:
- Install ferrite beads near the MCU.
- Use twisted pair wiring with chassis ground.
- Keep the bus terminated at both ends.

**Section sources**
- [README.md:22-41](file://README.md#L22-L41)
- [platformio.ini:12-15](file://platformio.ini#L12-L15)

### Bus-Off Recovery Procedures
Symptoms:
- CAN controller enters bus-off state
- No TX frames; RX may still work

Root causes:
- Excessive bus errors due to electrical faults or overload

Resolution procedure:
1. Wait for automatic TWAI recovery; the stack handles bus-off recovery.
2. If persistent, power cycle the device to reset the controller.
3. Investigate root cause (wiring, load, noise) before re-enabling operation.

Preventive measures:
- Avoid connecting faulty devices to the bus.
- Ensure proper termination and signal integrity.

**Section sources**
- [README.md:109-110](file://README.md#L109-L110)

### I2C Communication Failures with PCA9685
Symptoms:
- PCA9685 not detected
- Partial channel control or flickering
- Runtime errors during initialization

Root causes:
- Incorrect SDA/SCL pin assignments
- Pull-up resistors missing or insufficient
- I2C bus speed mismatch
- Address conflict with other devices

Resolution procedure:
1. Confirm SDA/SCL pin defines match hardware.
2. Install 4.7 kΩ pull-ups to 3.3 V on both lines.
3. Verify no other I2C devices share conflicting addresses.
4. Use an I2C scanner to validate bus presence.
5. Reinitialize PCA9685 after correcting wiring.

Preventive measures:
- Use shielded I2C cables for long runs.
- Keep I2C bus length under 1 meter for reliability.

**Section sources**
- [platformio.ini:26-28](file://platformio.ini#L26-L28)
- [ecu_motor_driver.cpp:85-99](file://src/ecu_motor_driver.cpp#L85-L99)

### Web Interface Connectivity Issues
Symptoms:
- Cannot reach the web UI at 192.168.4.1 or hostname.local
- Dashboard shows no data
- OTA tab reports network errors

Root causes:
- Wi-Fi AP disabled or mDNS not responding
- Host firewall blocking local DNS
- Incorrect hostname or AP credentials

Resolution procedure:
1. Ensure OTA build flags are enabled for the environment.
2. Connect to the AP named after the device (e.g., forwarder-motor-XX).
3. Access http://192.168.4.1 or http://<hostname>.local.
4. Verify mDNS service registration and browse .local domains.
5. Check browser console for CORS or mixed-content warnings.

Preventive measures:
- Use unique hostnames derived from device address.
- Keep AP password consistent across builds.

**Section sources**
- [README.md:84-98](file://README.md#L84-L98)
- [platformio.ini:63-79](file://platformio.ini#L63-L79)
- [ota_webserver.cpp:766-791](file://src/ota_webserver.cpp#L766-L791)

### WiFi OTA Update Failures
Symptoms:
- Upload progress reaches 100% but update fails
- Device does not reboot into new firmware
- Error message indicates update failure

Root causes:
- Corrupted firmware image
- Insufficient free flash space
- Interrupted upload or network instability
- Update.handle() not invoked properly

Resolution procedure:
1. Recompile firmware and verify .bin size.
2. Ensure sufficient free space on device.
3. Retry upload using a wired Ethernet adapter or stable Wi-Fi.
4. Check serial logs for Update errors and retry.
5. If the device does not reboot, power cycle manually.

Preventive measures:
- Validate firmware images before flashing.
- Avoid power interruptions during OTA.

**Section sources**
- [README.md:88-103](file://README.md#L88-L103)
- [ota_webserver.cpp:705-737](file://src/ota_webserver.cpp#L705-L737)

### Configuration Corruption
Symptoms:
- Unexpected address changes
- Lost axis mapping or CAN output rules
- Device behavior differs after power loss

Root causes:
- Power loss during writes
- Flash wear or write errors
- Incorrect configuration keys

Resolution procedure:
1. Reset configuration by clearing stored values via web UI or by reflashing without saved config.
2. Re-apply axis mapping and CAN output rules.
3. Save configuration from the web UI to persist settings.

Preventive measures:
- Avoid abrupt power removal during configuration changes.
- Use stable power supplies and consider backup strategies if applicable.

**Section sources**
- [ecu_motor_driver.cpp:297-300](file://src/ecu_motor_driver.cpp#L297-L300)
- [ecu_joystick.cpp:171-172](file://src/ecu_joystick.cpp#L171-L172)
- [ota_webserver.cpp:587-626](file://src/ota_webserver.cpp#L587-L626)

## Dependency Analysis
The ECU implementations depend on shared libraries and hardware pins defined by build flags. The OTA web server depends on Wi-Fi, mDNS, and HTTP libraries.

```mermaid
graph LR
Flags["Build Flags<br/>platformio.ini"] --> MD["Motor Driver ECU"]
Flags --> JY["Joystick ECU"]
MD --> CAN["ForwarderCAN.h"]
JY --> CAN
MD --> CFG["ForwarderConfig.h"]
JY --> CFG
MD --> I2C["PCA9685 I2C"]
MD --> OTA["ota_webserver.cpp"]
JY --> OTA
```

**Diagram sources**
- [platformio.ini:17-80](file://platformio.ini#L17-L80)
- [ecu_motor_driver.cpp:9-12](file://src/ecu_motor_driver.cpp#L9-L12)
- [ecu_joystick.cpp:6-9](file://src/ecu_joystick.cpp#L6-L9)
- [ota_webserver.cpp:5-11](file://src/ota_webserver.cpp#L5-L11)

**Section sources**
- [platformio.ini:12-15](file://platformio.ini#L12-L15)
- [ecu_motor_driver.cpp:9-12](file://src/ecu_motor_driver.cpp#L9-L12)
- [ecu_joystick.cpp:6-9](file://src/ecu_joystick.cpp#L6-L9)

## Performance Considerations
- CAN bus utilization: Keep message rates reasonable to avoid congestion.
- I2C bus speed: PCA9685 operates at 200 Hz; ensure adequate I2C timing margins.
- Watchdog timeouts: Short watchdog resets solenoids; maintain periodic joystick updates.
- OTA bandwidth: Large firmware images may take several seconds; ensure stable connection.

## Troubleshooting Guide

### Quick Reference Solutions
- Address collision resolved via arbitration; confirm unique address in dashboard
- Safety timeout disables outputs; send joystick data to re-enable
- PCA9685 not detected; verify SDA/SCL, pull-ups, and addresses
- OTA upload fails; reflash with validated .bin and retry
- Web UI unreachable; connect to AP and access 192.168.4.1 or hostname.local

### Escalation Procedures
- If bus-off persists, investigate wiring and load; replace transceiver if necessary
- If configuration corruption recurs, check power stability and avoid abrupt power removal
- If heartbeat anomalies continue, use a bus analyzer to validate frame integrity

## Conclusion
ForwarderKE’s design leverages J1939-style addressing, heartbeat monitoring, and safety timeouts to deliver reliable operation. Most issues stem from wiring, I2C configuration, or OTA connectivity. By following the diagnostic steps and preventive measures outlined here, most problems can be resolved quickly. For persistent issues, escalate to deeper diagnostics using oscilloscopes, bus analyzers, and serial logs.

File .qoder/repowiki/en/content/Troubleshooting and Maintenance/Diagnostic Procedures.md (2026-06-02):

# Diagnostic Procedures

<cite>
**Referenced Files in This Document**
- [README.md](file://README.md)
- [platformio.ini](file://platformio.ini)
- [src/main.cpp](file://src/main.cpp)
- [src/ecu_motor_driver.cpp](file://src/ecu_motor_driver.cpp)
- [src/ecu_joystick.cpp](file://src/ecu_joystick.cpp)
- [src/can_output.cpp](file://src/can_output.cpp)
- [src/web_state.h](file://src/web_state.h)
- [src/ota_webserver.cpp](file://src/ota_webserver.cpp)
- [lib/ForwarderCAN/ForwarderCAN.h](file://lib/ForwarderCAN/ForwarderCAN.h)
</cite>

## Table of Contents
1. [Introduction](#introduction)
2. [Project Structure](#project-structure)
3. [Core Components](#core-components)
4. [Architecture Overview](#architecture-overview)
5. [Detailed Component Analysis](#detailed-component-analysis)
6. [Dependency Analysis](#dependency-analysis)
7. [Performance Considerations](#performance-considerations)
8. [Troubleshooting Guide](#troubleshooting-guide)
9. [Conclusion](#conclusion)
10. [Appendices](#appendices)

## Introduction
This document provides comprehensive diagnostic procedures for ForwarderKE, focusing on systematic troubleshooting methodologies and diagnostic tools. It covers CAN bus communication diagnostics using oscilloscope measurements, serial debug output interpretation, and heartbeat monitoring analysis. It also explains built-in diagnostic capabilities such as error counters, status reporting, and system health indicators, and outlines diagnostic workflows to identify hardware faults, software bugs, and configuration issues. Step-by-step procedures are included for measuring CAN bus signal integrity, analyzing message traffic patterns, and interpreting system status messages. Guidance is provided for using serial monitors for real-time debugging, log analysis techniques, and performance monitoring. Finally, diagnostic checklists are included for common failure scenarios and systematic approaches to isolate problems in multi-ECU CAN bus systems.

## Project Structure
ForwarderKE consists of:
- A shared CAN/J1939 library implementing ID layout, message parsing, and statistics.
- An application entry point selecting the ECU type at build time.
- Two ECU implementations:
  - Motor driver ECU controlling solenoids via PCA9685 and broadcasting heartbeat/status.
  - Joystick ECU reading analog inputs and buttons and publishing joystick data.
- Optional OTA web server exposing runtime telemetry and configuration.
- CAN output rules enabling GPIO toggling or momentary pulses based on incoming CAN messages.

```mermaid
graph TB
A["src/main.cpp<br/>Entry point"] --> B["src/ecu_motor_driver.cpp<br/>Motor driver ECU"]
A --> C["src/ecu_joystick.cpp<br/>Joystick ECU"]
B --> D["lib/ForwarderCAN/ForwarderCAN.h<br/>CAN/J1939 library"]
C --> D
B --> E["src/can_output.cpp<br/>CAN-triggered GPIO rules"]
F["src/ota_webserver.cpp<br/>OTA web UI"] --> B
F --> C
G["src/web_state.h<br/>Shared runtime state"] --> B
G --> C
```

**Diagram sources**
- [src/main.cpp:11-17](file://src/main.cpp#L11-L17)
- [src/ecu_motor_driver.cpp:290-325](file://src/ecu_motor_driver.cpp#L290-L325)
- [src/ecu_joystick.cpp:159-192](file://src/ecu_joystick.cpp#L159-L192)
- [lib/ForwarderCAN/ForwarderCAN.h:66-119](file://lib/ForwarderCAN/ForwarderCAN.h#L66-L119)
- [src/can_output.cpp:7-19](file://src/can_output.cpp#L7-L19)
- [src/ota_webserver.cpp:506-517](file://src/ota_webserver.cpp#L506-L517)
- [src/web_state.h:10-23](file://src/web_state.h#L10-L23)

**Section sources**
- [README.md:112-126](file://README.md#L112-L126)
- [platformio.ini:1-80](file://platformio.ini#L1-L80)
- [src/main.cpp:11-17](file://src/main.cpp#L11-L17)

## Core Components
- ForwarderCAN: Implements J1939-like 29-bit ID layout, address claiming, send/receive, and statistics (TX/RX/error counts).
- Motor Driver ECU: Initializes PCA9685, maps joystick inputs to solenoid outputs, handles LED status, broadcasts heartbeat, and applies safety timeout.
- Joystick ECU: Reads analog pots/buttons, publishes joystick data, handles LED status, and broadcasts heartbeat.
- CAN Output Rules: Enables GPIO actions in response to matched CAN frames.
- OTA Web Server: Exposes JSON telemetry including online status, TX/RX/error counts, joystick data, solenoid values, and module discovery via heartbeat scanning.

Key diagnostic capabilities:
- Error counters and statistics exposed by ForwarderCAN.
- Heartbeat/status messages broadcast by all ECUs.
- Web UI telemetry for live inspection and module discovery.
- Address claiming and conflict handling for collision avoidance.

**Section sources**
- [lib/ForwarderCAN/ForwarderCAN.h:66-119](file://lib/ForwarderCAN/ForwarderCAN.h#L66-L119)
- [src/ecu_motor_driver.cpp:277-288](file://src/ecu_motor_driver.cpp#L277-L288)
- [src/ecu_joystick.cpp:146-157](file://src/ecu_joystick.cpp#L146-L157)
- [src/ota_webserver.cpp:510-517](file://src/ota_webserver.cpp#L510-L517)
- [src/ota_webserver.cpp:740-761](file://src/ota_webserver.cpp#L740-L761)

## Architecture Overview
The system operates on a 250 kbps CAN bus with J1939-like extended IDs. Three ECUs coexist:
- Motor Driver (address 0x20): Controls solenoids and broadcasts heartbeat/status.
- Joystick 1 (address 0x21): Publishes joystick data and heartbeat.
- Joystick 2 (address 0x22): Publishes joystick data and heartbeat.

```mermaid
graph TB
subgraph "CAN Bus (250 kbps)"
MD["Motor Driver ECU<br/>SA=0x20"]
J1["Joystick 1 ECU<br/>SA=0x21"]
J2["Joystick 2 ECU<br/>SA=0x22"]
end
MD --- J1
MD --- J2
J1 --- MD
J2 --- MD
```

**Diagram sources**
- [README.md:8-14](file://README.md#L8-L14)
- [README.md:22-41](file://README.md#L22-L41)

## Detailed Component Analysis

### ForwarderCAN Diagnostics
- Address claiming state machine and online status.
- Statistics: TX count, RX count, error count.
- Bus-off recovery and automatic TWAI recovery are supported by the underlying driver.

```mermaid
classDiagram
class ForwarderCAN {
+bool begin(txPin, rxPin, bitrate)
+void loop()
+bool send(pf, ps, data, len, priority)
+bool sendBroadcast(pf, data, len, priority)
+bool receive(msg, timeoutMs)
+bool hasMessage()
+bool isOnline()
+uint8_t getAddress()
+uint32_t getTxCount()
+uint32_t getRxCount()
+uint32_t getErrorCount()
}
```

**Diagram sources**
- [lib/ForwarderCAN/ForwarderCAN.h:66-119](file://lib/ForwarderCAN/ForwarderCAN.h#L66-L119)

**Section sources**
- [lib/ForwarderCAN/ForwarderCAN.h:94-96](file://lib/ForwarderCAN/ForwarderCAN.h#L94-L96)
- [README.md:105-110](file://README.md#L105-L110)

### Motor Driver ECU Diagnostics
- Initializes PCA9685, detects dual PCA9685, and maps joystick inputs to solenoid outputs.
- Safety timeout turns off solenoids if no commands are received within the configured interval.
- LED status indicates online/offline, heartbeat blink pattern, and identification mode.
- Heartbeat payload includes online flag, uptime, RX/TX counts, and device-specific flags.

```mermaid
sequenceDiagram
participant MD as "Motor Driver ECU"
participant CAN as "ForwarderCAN"
participant PCA as "PCA9685"
participant LED as "Status LED"
MD->>CAN : "begin(tx, rx, bitrate)"
CAN-->>MD : "OK or FAIL"
MD->>PCA : "init and set frequency"
MD->>MD : "load config and output rules"
loop Every 1s
MD->>CAN : "sendBroadcast(PF_HEARTBEAT, payload)"
CAN-->>MD : "ack"
end
MD->>CAN : "receive()"
CAN-->>MD : "CANMessage"
MD->>PCA : "setPWM(channel, value)"
MD->>LED : "update color/brightness"
```

**Diagram sources**
- [src/ecu_motor_driver.cpp:290-325](file://src/ecu_motor_driver.cpp#L290-L325)
- [src/ecu_motor_driver.cpp:327-352](file://src/ecu_motor_driver.cpp#L327-L352)
- [src/ecu_motor_driver.cpp:277-288](file://src/ecu_motor_driver.cpp#L277-L288)

**Section sources**
- [src/ecu_motor_driver.cpp:32-34](file://src/ecu_motor_driver.cpp#L32-L34)
- [src/ecu_motor_driver.cpp:78-83](file://src/ecu_motor_driver.cpp#L78-L83)
- [src/ecu_motor_driver.cpp:137-151](file://src/ecu_motor_driver.cpp#L137-L151)
- [src/ecu_motor_driver.cpp:332-337](file://src/ecu_motor_driver.cpp#L332-L337)
- [src/ecu_motor_driver.cpp:153-182](file://src/ecu_motor_driver.cpp#L153-L182)
- [src/ecu_motor_driver.cpp:277-288](file://src/ecu_motor_driver.cpp#L277-L288)

### Joystick ECU Diagnostics
- Reads analog pots/buttons with defined pins and thresholds.
- Publishes joystick data periodically or on change.
- LED status reflects online/offline and identification mode.
- Heartbeat payload includes online flag, uptime, and joystick identity.

```mermaid
sequenceDiagram
participant JS as "Joystick ECU"
participant CAN as "ForwarderCAN"
participant LED as "Status LED"
JS->>CAN : "begin(tx, rx, bitrate)"
CAN-->>JS : "OK or FAIL"
loop Every ~100ms
JS->>JS : "readInputs()"
JS->>CAN : "sendBroadcast(PF_JOYSTICK_POT1/2, data)"
JS->>CAN : "sendBroadcast(PF_JOYSTICK_BUTTONS, data)"
end
loop Every 1s
JS->>CAN : "sendBroadcast(PF_HEARTBEAT, payload)"
CAN-->>JS : "ack"
end
JS->>CAN : "receive()"
CAN-->>JS : "CANMessage"
JS->>LED : "update color/brightness"
```

**Diagram sources**
- [src/ecu_joystick.cpp:159-192](file://src/ecu_joystick.cpp#L159-L192)
- [src/ecu_joystick.cpp:194-236](file://src/ecu_joystick.cpp#L194-L236)
- [src/ecu_joystick.cpp:146-157](file://src/ecu_joystick.cpp#L146-L157)

**Section sources**
- [src/ecu_joystick.cpp:63-68](file://src/ecu_joystick.cpp#L63-L68)
- [src/ecu_joystick.cpp:198-225](file://src/ecu_joystick.cpp#L198-L225)
- [src/ecu_joystick.cpp:146-157](file://src/ecu_joystick.cpp#L146-L157)

### CAN Output Rules Diagnostics
- Configurable rules match PF/SA and trigger GPIO actions.
- Toggle mode flips output state per match.
- Momentary mode sets output HIGH then reverts after a timer.

```mermaid
flowchart TD
Start(["Receive CAN frame"]) --> Decode["Decode PF/SA"]
Decode --> Match{"Rule matches?<br/>PF and optional SA"}
Match --> |No| End(["Ignore"])
Match --> |Yes| Mode{"Mode = toggle or momentary"}
Mode --> |Toggle| Toggle["Flip output state"]
Mode --> |Momentary| Pulse["Set HIGH, start timer"]
Pulse --> TimerCheck{"Timer elapsed?"}
TimerCheck --> |No| End
TimerCheck --> |Yes| Reset["Set LOW"]
Toggle --> End
Reset --> End
```

**Diagram sources**
- [src/can_output.cpp:29-49](file://src/can_output.cpp#L29-L49)
- [src/can_output.cpp:51-61](file://src/can_output.cpp#L51-L61)

**Section sources**
- [src/can_output.cpp:7-19](file://src/can_output.cpp#L7-L19)
- [src/can_output.cpp:29-49](file://src/can_output.cpp#L29-L49)
- [src/can_output.cpp:51-61](file://src/can_output.cpp#L51-L61)

### OTA Web Server Diagnostics
- Exposes JSON telemetry including local address, online status, uptime, TX/RX/error counts, joystick data, solenoid values, and discovered modules via heartbeat scanning.
- Heartbeat scanner inspects heartbeat frames to infer module type and last-seen time.

```mermaid
sequenceDiagram
participant Browser as "Browser"
participant OTA as "OTA Web Server"
participant CAN as "ForwarderCAN"
participant MD as "Motor Driver ECU"
participant JS as "Joystick ECU"
Browser->>OTA : "GET /"
OTA-->>Browser : "HTML + JS"
loop Every 200ms
Browser->>OTA : "GET /state"
OTA->>CAN : "getAddress()/isOnline()/getTxCount()/getRxCount()/getErrorCount()"
CAN-->>OTA : "values"
OTA->>MD : "read joystick/solenoid arrays"
OTA->>JS : "read local joystick data"
OTA-->>Browser : "JSON telemetry"
OTA->>CAN : "receive()"
CAN-->>OTA : "heartbeat frames"
OTA->>OTA : "scanHeartbeats() to discover modules"
end
```

**Diagram sources**
- [src/ota_webserver.cpp:510-517](file://src/ota_webserver.cpp#L510-L517)
- [src/ota_webserver.cpp:740-761](file://src/ota_webserver.cpp#L740-L761)

**Section sources**
- [src/ota_webserver.cpp:510-517](file://src/ota_webserver.cpp#L510-L517)
- [src/ota_webserver.cpp:740-761](file://src/ota_webserver.cpp#L740-L761)

## Dependency Analysis
- ECU selection is compile-time via build flags; main dispatches to the appropriate ECU implementation.
- Both ECUs depend on ForwarderCAN for transport and statistics.
- Motor driver depends on PCA9685 drivers and NeoPixel for LEDs.
- OTA web server depends on ForwarderCAN and shared runtime state.

```mermaid
graph LR
M["src/main.cpp"] --> EM["src/ecu_motor_driver.cpp"]
M --> EJ["src/ecu_joystick.cpp"]
EM --> FC["lib/ForwarderCAN/ForwarderCAN.h"]
EJ --> FC
EM --> CO["src/can_output.cpp"]
OTA["src/ota_webserver.cpp"] --> FC
OTA --> WS["src/web_state.h"]
```

**Diagram sources**
- [src/main.cpp:11-17](file://src/main.cpp#L11-L17)
- [src/ecu_motor_driver.cpp:1-12](file://src/ecu_motor_driver.cpp#L1-L12)
- [src/ecu_joystick.cpp:1-9](file://src/ecu_joystick.cpp#L1-L9)
- [src/can_output.cpp:1-5](file://src/can_output.cpp#L1-L5)
- [src/ota_webserver.cpp:1-10](file://src/ota_webserver.cpp#L1-L10)
- [src/web_state.h:1-6](file://src/web_state.h#L1-L6)

**Section sources**
- [src/main.cpp:11-17](file://src/main.cpp#L11-L17)
- [platformio.ini:12-15](file://platformio.ini#L12-L15)

## Performance Considerations
- CAN bitrate is fixed at 250 kbps; ensure bus termination and wiring meet ISO 11898 standards.
- Heartbeat broadcast occurs every 1 second; monitor RX/TX counts to detect anomalies.
- Safety timeout disables solenoids after inactivity; tune SAFETY_TIMEOUT_MS as needed.
- PCA9685 frequency and PWM resolution impact solenoid response; verify oscillator settings.

[No sources needed since this section provides general guidance]

## Troubleshooting Guide

### CAN Bus Communication Diagnostics
- Oscilloscope measurements:
  - Measure CAN_H and CAN_L differential voltage swing; typical J1939 at 250 kbps expects around 2.5 Vpp at the receiver input.
  - Verify signal integrity: eye diagram opening, rise/fall times, and jitter.
  - Check for bus terminations (120 Ω) at both ends of the bus.
  - Inspect for dominant and recessive signaling; confirm proper arbitration and ACK zones.
- Serial debug output interpretation:
  - Monitor initialization logs for CAN begin success or failure.
  - Watch for LED patterns indicating online/offline, fast blinks (recent activity), and identification mode.
  - Track error counters via web telemetry to detect bus errors or bus-off conditions.
- Heartbeat monitoring analysis:
  - Use the heartbeat scanner to discover modules and infer types from payload fields.
  - Validate uptime increments and RX/TX counts growth to confirm normal operation.

**Section sources**
- [src/ecu_motor_driver.cpp:306-316](file://src/ecu_motor_driver.cpp#L306-L316)
- [src/ecu_joystick.cpp:175-185](file://src/ecu_joystick.cpp#L175-L185)
- [src/ecu_motor_driver.cpp:153-182](file://src/ecu_motor_driver.cpp#L153-L182)
- [src/ecu_joystick.cpp:89-97](file://src/ecu_joystick.cpp#L89-L97)
- [src/ota_webserver.cpp:510-517](file://src/ota_webserver.cpp#L510-L517)
- [src/ota_webserver.cpp:740-761](file://src/ota_webserver.cpp#L740-L761)

### Built-in Diagnostic Capabilities
- Error counters and status reporting:
  - Access TX/RX/error counts via ForwarderCAN getters and web telemetry endpoints.
  - Use heartbeat payloads to inspect online status, uptime, and device-specific flags.
- System health indicators:
  - LED patterns reflect online/offline, recent activity, and identification mode.
  - Address claiming state transitions indicate collision handling.

**Section sources**
- [lib/ForwarderCAN/ForwarderCAN.h:94-96](file://lib/ForwarderCAN/ForwarderCAN.h#L94-L96)
- [src/ota_webserver.cpp:510-517](file://src/ota_webserver.cpp#L510-L517)
- [src/ecu_motor_driver.cpp:277-288](file://src/ecu_motor_driver.cpp#L277-L288)
- [src/ecu_joystick.cpp:146-157](file://src/ecu_joystick.cpp#L146-L157)

### Diagnostic Workflow
- Isolate hardware faults:
  - Verify power and ground connections to MCU and PCA9685.
  - Confirm CAN transceiver enable pin configuration and wiring continuity.
  - Check LED behavior during initialization and runtime.
- Identify software bugs:
  - Compare TX/RX/error counts over time; rising error counts suggest framing or bit errors.
  - Validate heartbeat presence and type inference via heartbeat scanner.
  - Inspect CAN output rule behavior against expected PF/SA matches.
- Resolve configuration issues:
  - Use address claiming and forced address settings to avoid conflicts.
  - Adjust axis mapping and deadband parameters via configuration requests and responses.

**Section sources**
- [src/ecu_motor_driver.cpp:234-245](file://src/ecu_motor_driver.cpp#L234-L245)
- [src/ecu_joystick.cpp:132-142](file://src/ecu_joystick.cpp#L132-L142)
- [src/ecu_motor_driver.cpp:257-267](file://src/ecu_motor_driver.cpp#L257-L267)
- [src/ecu_motor_driver.cpp:298-300](file://src/ecu_motor_driver.cpp#L298-L300)

### Measuring CAN Bus Signal Integrity
- Steps:
  - Connect oscilloscope probes across CAN_H/CAN_L.
  - Set bandwidth limit and measure peak-to-peak voltage.
  - Observe the waveform shape during dominant and recessive states.
  - Validate timing parameters (bit timing, sampling points).
  - Check for reflections and noise by inspecting overshoot/undershoot.

**Section sources**
- [README.md:16-21](file://README.md#L16-L21)
- [platformio.ini:12-15](file://platformio.ini#L12-L15)

### Analyzing Message Traffic Patterns
- Steps:
  - Capture heartbeats and joystick frames using the heartbeat scanner and serial logs.
  - Correlate joystick pot values with solenoid outputs to verify mapping.
  - Monitor error counters to detect malformed frames or bus off events.
  - Validate address claiming and conflict resolution behavior.

**Section sources**
- [src/ota_webserver.cpp:740-761](file://src/ota_webserver.cpp#L740-L761)
- [src/ecu_motor_driver.cpp:184-275](file://src/ecu_motor_driver.cpp#L184-L275)
- [src/ecu_joystick.cpp:114-144](file://src/ecu_joystick.cpp#L114-L144)

### Interpreting System Status Messages
- Steps:
  - Parse heartbeat payload fields to extract online flag, uptime, RX/TX counts, and device-specific flags.
  - Use web telemetry to correlate joystick ages and solenoid values with system health.
  - Cross-reference LED behavior with online/offline states and recent activity.

**Section sources**
- [src/ecu_motor_driver.cpp:277-288](file://src/ecu_motor_driver.cpp#L277-L288)
- [src/ecu_joystick.cpp:146-157](file://src/ecu_joystick.cpp#L146-L157)
- [src/ota_webserver.cpp:510-517](file://src/ota_webserver.cpp#L510-L517)

### Using Serial Monitors for Real-Time Debugging
- Steps:
  - Open serial monitor at 115200 baud.
  - Observe initialization logs for CAN begin success/failure and PCA9685 detection.
  - Watch for LED updates and periodic heartbeat transmissions.
  - Monitor error counters and address claiming state transitions.

**Section sources**
- [platformio.ini:8](file://platformio.ini#L8)
- [src/ecu_motor_driver.cpp:294-318](file://src/ecu_motor_driver.cpp#L294-L318)
- [src/ecu_joystick.cpp:163-186](file://src/ecu_joystick.cpp#L163-L186)

### Log Analysis Techniques
- Steps:
  - Export serial logs and parse initialization, error, and operational messages.
  - Track TX/RX/error counts over time to identify trends.
  - Correlate LED patterns with reported online/offline states.

**Section sources**
- [src/ecu_motor_driver.cpp:306-316](file://src/ecu_motor_driver.cpp#L306-L316)
- [src/ecu_joystick.cpp:175-185](file://src/ecu_joystick.cpp#L175-L185)

### Performance Monitoring Procedures
- Steps:
  - Monitor heartbeat intervals and uptime increments.
  - Track RX/TX counts growth to ensure normal traffic.
  - Observe LED behavior for quick health assessment.

**Section sources**
- [src/ecu_motor_driver.cpp:341-346](file://src/ecu_motor_driver.cpp#L341-L346)
- [src/ecu_joystick.cpp:226-231](file://src/ecu_joystick.cpp#L226-L231)

### Diagnostic Checklists for Common Failure Scenarios
- Address collision or claiming failure:
  - Verify preferred address and forced address settings.
  - Confirm address claiming state transitions and retries.
- Bus errors or bus-off:
  - Check error counters and heartbeat presence.
  - Inspect oscilloscope traces for signal integrity issues.
- Solenoid inactivity or timeout:
  - Validate joystick input mapping and axis configuration.
  - Confirm heartbeat presence and recent joystick updates.
- OTA update failures:
  - Verify Wi-Fi AP availability and web UI accessibility.
  - Confirm successful upload and reboot sequence.

**Section sources**
- [src/ecu_motor_driver.cpp:298-300](file://src/ecu_motor_driver.cpp#L298-L300)
- [src/ecu_motor_driver.cpp:332-337](file://src/ecu_motor_driver.cpp#L332-L337)
- [src/ota_webserver.cpp:766-777](file://src/ota_webserver.cpp#L766-L777)

## Conclusion
ForwarderKE provides robust built-in diagnostics through CAN statistics, heartbeat/status messages, LED indicators, and an optional OTA web UI. Systematic troubleshooting should combine oscilloscope measurements, serial log analysis, and heartbeat monitoring to quickly isolate hardware, software, and configuration issues. The provided workflows and checklists offer structured approaches to diagnosing multi-ECU CAN bus systems effectively.

[No sources needed since this section summarizes without analyzing specific files]

## Appendices

### CAN Protocol Reference
- J1939-like extended ID layout and PF definitions used by ForwarderKE.
- Message types for joystick data, LED control, solenoid commands, and heartbeat/status.

**Section sources**
- [README.md:22-41](file://README.md#L22-L41)

### Build and Flashing Context
- Build environments for motor driver, joystick variants, and OTA-enabled builds.
- Pin assignments and peripheral configurations per ECU type.

**Section sources**
- [platformio.ini:17-80](file://platformio.ini#L17-L80)
- [README.md:48-62](file://README.md#L48-L62)

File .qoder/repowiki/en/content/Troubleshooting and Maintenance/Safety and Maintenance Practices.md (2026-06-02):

# Safety and Maintenance Practices

<cite>
**Referenced Files in This Document**
- [README.md](file://README.md)
- [platformio.ini](file://platformio.ini)
- [main.cpp](file://src/main.cpp)
- [ecu_motor_driver.cpp](file://src/ecu_motor_driver.cpp)
- [ecu_joystick.cpp](file://src/ecu_joystick.cpp)
- [ota_webserver.cpp](file://src/ota_webserver.cpp)
- [web_state.h](file://src/web_state.h)
- [can_output.h](file://src/can_output.h)
</cite>

## Table of Contents
1. [Introduction](#introduction)
2. [Project Structure](#project-structure)
3. [Core Components](#core-components)
4. [Architecture Overview](#architecture-overview)
5. [Detailed Component Analysis](#detailed-component-analysis)
6. [Dependency Analysis](#dependency-analysis)
7. [Performance Considerations](#performance-considerations)
8. [Troubleshooting Guide](#troubleshooting-guide)
9. [Conclusion](#conclusion)
10. [Appendices](#appendices)

## Introduction
This document provides comprehensive safety guidelines and maintenance practices for ForwarderKE systems. It consolidates the built-in safety features present in the codebase (address claiming arbitration, solenoid timeout protection, bus-off recovery, and heartbeat monitoring), outlines safe operational procedures for CAN bus systems and electrical hazards, and defines preventive maintenance schedules for field-deployed units. It also includes shutdown procedures, power cycling protocols, ESD precautions, grounding practices, environmental protection, and long-term storage recommendations. Finally, it provides safety checklists for installation, operation, and decommissioning.

## Project Structure
The ForwarderKE system consists of:
- An ESP32-S3-based MCU running either a motor driver ECU or a joystick ECU.
- A shared CAN/J1939-like protocol stack for inter-ECU communication.
- Optional Wi-Fi OTA update capability for firmware updates.
- A web UI for diagnostics, configuration, and OTA updates.

```mermaid
graph TB
subgraph "ECUs"
MD["Motor Driver ECU<br/>PCA9685 PWM outputs"]
J1["Joystick ECU 1<br/>3 pots + 2 buttons"]
J2["Joystick ECU 2<br/>3 pots + 2 buttons"]
end
CAN["CAN Bus 250 kbps<br/>J1939-like IDs"]
WEB["OTA Web UI<br/>Wi-Fi AP + HTTP server"]
MD --> CAN
J1 --> CAN
J2 --> CAN
WEB --> MD
WEB --> J1
WEB --> J2
```

**Diagram sources**
- [README.md:8-14](file://README.md#L8-L14)
- [platformio.ini:17-61](file://platformio.ini#L17-L61)
- [ota_webserver.cpp:766-791](file://src/ota_webserver.cpp#L766-L791)

**Section sources**
- [README.md:6-14](file://README.md#L6-L14)
- [platformio.ini:17-61](file://platformio.ini#L17-L61)

## Core Components
- Address claiming and arbitration: Ensures unique addresses at startup using J1939-style ID fields.
- Solenoid timeout protection: Automatically turns off solenoids after a period without CAN commands.
- Bus-off recovery: Uses automatic TWAI recovery on CAN bus errors.
- Heartbeat monitoring: All ECUs broadcast periodic status messages.

These features are implemented across the motor driver and joystick ECUs and are complemented by the OTA web UI for diagnostics and updates.

**Section sources**
- [README.md:105-110](file://README.md#L105-L110)
- [ecu_motor_driver.cpp:332-337](file://src/ecu_motor_driver.cpp#L332-L337)
- [ecu_motor_driver.cpp:277-288](file://src/ecu_motor_driver.cpp#L277-L288)
- [ecu_joystick.cpp:146-157](file://src/ecu_joystick.cpp#L146-L157)

## Architecture Overview
The system uses a centralized CAN bus with three ECUs:
- Motor Driver ECU (address 0x20): Controls 8 solenoids via PCA9685 PWM channels.
- Joystick ECU 1 (address 0x21): Publishes joystick and button data.
- Joystick ECU 2 (address 0x22): Publishes joystick and button data.

Each ECU initializes its CAN interface, performs address claiming, and periodically broadcasts heartbeat/status frames. The OTA web UI provides diagnostics and firmware updates.

```mermaid
sequenceDiagram
participant MD as "Motor Driver ECU"
participant J1 as "Joystick ECU 1"
participant J2 as "Joystick ECU 2"
participant CAN as "CAN Bus"
MD->>CAN : "Send Heartbeat"
J1->>CAN : "Send Heartbeat"
J2->>CAN : "Send Heartbeat"
J1->>CAN : "Send Pot1/Pot2/Pot3/Button frames"
J2->>CAN : "Send Pot1/Pot2/Pot3/Button frames"
CAN-->>MD : "Solenoid Command frames"
MD->>MD : "Apply PWM to solenoids"
MD->>CAN : "Send Heartbeat"
```

**Diagram sources**
- [README.md:29-41](file://README.md#L29-L41)
- [ecu_motor_driver.cpp:184-275](file://src/ecu_motor_driver.cpp#L184-L275)
- [ecu_joystick.cpp:114-144](file://src/ecu_joystick.cpp#L114-L144)

## Detailed Component Analysis

### Address Claiming Arbitration
- Purpose: Prevents address conflicts during startup.
- Mechanism: Each ECU publishes an address claim frame at startup and listens for others. If a conflict is detected, the ECU with the lower preferred address retains it; the other reverts to a safe state and restarts.
- Behavior: Address selection is compile-time via build flags; runtime enforcement occurs during CAN initialization.

```mermaid
flowchart TD
Start(["Startup"]) --> InitCAN["Initialize CAN with preferred address"]
InitCAN --> Claim["Send Address Claim frame"]
Claim --> Listen["Listen for conflicting claims"]
Listen --> Conflict{"Conflict detected?"}
Conflict --> |No| Ready["Operational with selected address"]
Conflict --> |Yes| Resolve["Retain lower preferred address<br/>or force new address"]
Resolve --> Restart["Restart with chosen address"]
Ready --> End(["Run"])
Restart --> InitCAN
```

**Diagram sources**
- [ecu_motor_driver.cpp:290-325](file://src/ecu_motor_driver.cpp#L290-L325)
- [ecu_joystick.cpp:159-192](file://src/ecu_joystick.cpp#L159-L192)
- [platformio.ini:18-30](file://platformio.ini#L18-L30)

**Section sources**
- [README.md:105-107](file://README.md#L105-L107)
- [platformio.ini:18-30](file://platformio.ini#L18-L30)

### Solenoid Timeout Protection
- Purpose: Prevent unintended actuation if communication fails.
- Mechanism: The motor driver ECU monitors the last solenoid update time. If no command is received within the configured timeout, it turns off all solenoids and resets the timer.
- Configuration: Timeout is defined per environment via build flags.

```mermaid
flowchart TD
Entry(["Loop"]) --> CheckCmd["Has solenoid command arrived recently?"]
CheckCmd --> |Yes| Apply["Apply PWM to solenoids"]
CheckCmd --> |No| Timeout{"Exceeded timeout?"}
Timeout --> |No| Wait["Continue monitoring"]
Timeout --> |Yes| AllOff["Turn off all solenoids"]
Apply --> Wait
AllOff --> Wait
```

**Diagram sources**
- [ecu_motor_driver.cpp:327-352](file://src/ecu_motor_driver.cpp#L327-L352)
- [platformio.ini:29](file://platformio.ini#L29)

**Section sources**
- [README.md:108](file://README.md#L108)
- [platformio.ini:29](file://platformio.ini#L29)

### Bus-Off Recovery
- Purpose: Restore normal operation after bus-off conditions caused by excessive CAN errors.
- Mechanism: The underlying CAN driver automatically recovers from bus-off; the system continues normal operation after recovery.

```mermaid
flowchart TD
Start(["CAN Error Detected"]) --> BusOff{"Bus-off?"}
BusOff --> |No| LogErr["Log error counter increment"]
BusOff --> |Yes| AutoRecover["Automatic TWAI recovery"]
AutoRecover --> Resume["Resume normal operation"]
LogErr --> Resume
```

**Diagram sources**
- [README.md:109](file://README.md#L109)

**Section sources**
- [README.md:109](file://README.md#L109)

### Heartbeat Monitoring
- Purpose: Provide health and status visibility across the network.
- Mechanism: Each ECU periodically sends a heartbeat frame containing online status, uptime, and counters. The OTA web UI scans heartbeats to discover and track modules.

```mermaid
sequenceDiagram
participant ECU as "Any ECU"
participant CAN as "CAN Bus"
participant UI as "OTA Web UI"
ECU->>CAN : "Send Heartbeat"
UI->>CAN : "Receive Heartbeat"
UI->>UI : "Update module list and status"
```

**Diagram sources**
- [ecu_motor_driver.cpp:277-288](file://src/ecu_motor_driver.cpp#L277-L288)
- [ecu_joystick.cpp:146-157](file://src/ecu_joystick.cpp#L146-L157)
- [ota_webserver.cpp:742-761](file://src/ota_webserver.cpp#L742-L761)

**Section sources**
- [README.md:110](file://README.md#L110)
- [ota_webserver.cpp:506-563](file://src/ota_webserver.cpp#L506-L563)

### OTA Web UI and Diagnostics
- Purpose: Provide a browser-based interface for diagnostics, configuration, and firmware updates.
- Capabilities:
  - Real-time telemetry (joystick values, solenoid outputs, bus stats).
  - Module discovery and identification.
  - Remote configuration of axis mapping and CAN-triggered GPIO outputs.
  - Wi-Fi AP mode for OTA updates.

```mermaid
sequenceDiagram
participant User as "User Browser"
participant AP as "Wi-Fi AP"
participant Web as "OTA Web Server"
participant CAN as "CAN Bus"
participant ECU as "Target ECU"
User->>AP : "Connect to AP"
AP-->>User : "IP 192.168.4.1"
User->>Web : "Open /"
Web-->>User : "Dashboard UI"
User->>Web : "POST /update (firmware.bin)"
Web->>ECU : "Perform OTA update"
ECU-->>Web : "Reboot"
Web-->>User : "Success"
```

**Diagram sources**
- [README.md:84-103](file://README.md#L84-L103)
- [ota_webserver.cpp:766-791](file://src/ota_webserver.cpp#L766-L791)
- [ota_webserver.cpp:705-737](file://src/ota_webserver.cpp#L705-L737)

**Section sources**
- [README.md:84-103](file://README.md#L84-L103)
- [ota_webserver.cpp:506-563](file://src/ota_webserver.cpp#L506-L563)

## Dependency Analysis
- Build-time selection of ECU type and address via build flags.
- Runtime selection of CAN pins and peripherals via build flags.
- Shared CAN/J1939 protocol and configuration libraries used by both ECUs.
- Optional OTA web server adds Wi-Fi and HTTP dependencies.

```mermaid
graph LR
PIO["platformio.ini<br/>Build flags"] --> MD["ecu_motor_driver.cpp"]
PIO --> J1["ecu_joystick.cpp"]
PIO --> OTA["ota_webserver.cpp"]
MD --> CANLIB["ForwarderCAN.h"]
J1 --> CANLIB
MD --> CFG["ForwarderConfig.h"]
J1 --> CFG
OTA --> CANLIB
OTA --> CFG
```

**Diagram sources**
- [platformio.ini:12-15](file://platformio.ini#L12-L15)
- [platformio.ini:18-61](file://platformio.ini#L18-L61)
- [ecu_motor_driver.cpp:8-12](file://src/ecu_motor_driver.cpp#L8-L12)
- [ecu_joystick.cpp:6-9](file://src/ecu_joystick.cpp#L6-L9)
- [ota_webserver.cpp:5-11](file://src/ota_webserver.cpp#L5-L11)

**Section sources**
- [platformio.ini:12-15](file://platformio.ini#L12-L15)
- [platformio.ini:18-61](file://platformio.ini#L18-L61)

## Performance Considerations
- CAN bitrate is set to 250 kbps, balancing responsiveness and noise immunity.
- Heartbeat interval is 1 second, providing frequent health checks without heavy traffic.
- Watchdog timeout is configurable via build flags to balance responsiveness and stability.
- I2C bus speed and PCA9685 frequency are tuned for reliable PWM output.

[No sources needed since this section provides general guidance]

## Troubleshooting Guide
- CAN initialization failure: The system blinks an LED pattern and loops until fixed. Verify wiring, pins, and power.
- No joystick or solenoid activity: Confirm heartbeat reception and address claiming success.
- OTA update failures: Ensure correct .bin file, AP connectivity, and sufficient time for reboot after update.
- Bus errors: Monitor error counters and ensure proper termination and shielding.

**Section sources**
- [ecu_motor_driver.cpp:304-316](file://src/ecu_motor_driver.cpp#L304-L316)
- [ecu_joystick.cpp:174-185](file://src/ecu_joystick.cpp#L174-L185)
- [ota_webserver.cpp:705-737](file://src/ota_webserver.cpp#L705-L737)

## Conclusion
ForwarderKE incorporates robust built-in safety mechanisms—address arbitration, solenoid timeout protection, bus-off recovery, and heartbeat monitoring—alongside a practical OTA web UI for diagnostics and updates. Following the safety and maintenance practices outlined here will help ensure reliable operation, reduce risk, and prolong equipment life in field deployments.

[No sources needed since this section summarizes without analyzing specific files]

## Appendices

### Safety Protocols for CAN Bus Systems
- Never connect or disconnect CAN cables while powered on. Always power down the system before plugging/unplugging connectors.
- Use proper CAN termination resistors at both ends of the bus to minimize reflections and EMI.
- Keep CAN wires short and away from high-current cables to avoid noise coupling.
- Verify bus status via the web UI before powering up ECUs.

**Section sources**
- [ota_webserver.cpp:510-517](file://src/ota_webserver.cpp#L510-L517)

### Electrical Hazard Precautions
- Work only with de-energized circuits. Use lockout/tagout procedures when servicing.
- Use insulated tools and wear protective gloves.
- Avoid touching exposed pins or traces.

[No sources needed since this section provides general guidance]

### Proper Equipment Handling Procedures
- Transport units in anti-static bags.
- Avoid static discharge by touching grounded metal before handling boards.
- Handle only by edges; avoid touching connectors and ICs.

**Section sources**
- [README.md:18-20](file://README.md#L18-L20)

### Built-in Safety Features Summary
- Address claiming arbitration: Prevents address collisions at startup.
- Solenoid timeout protection: Shuts off outputs after inactivity.
- Bus-off recovery: Automatic recovery from bus-off errors.
- Heartbeat monitoring: Continuous health visibility.

**Section sources**
- [README.md:105-110](file://README.md#L105-L110)

### Preventive Maintenance Schedule
- Monthly
  - Visual inspection of housing, cable routing, and connector condition.
  - Verify LED indicators and web UI connectivity.
- Quarterly
  - Check and tighten terminal connections.
  - Inspect for dust, corrosion, or physical damage.
- Annually
  - Backup configuration and firmware images.
  - Validate heartbeat presence across all ECUs.
  - Perform a full power cycle test.

**Section sources**
- [ota_webserver.cpp:565-626](file://src/ota_webserver.cpp#L565-L626)

### Firmware Update Cycles
- Use OTA updates when necessary; ensure the device connects to its AP and upload a .bin file.
- After successful update, allow time for reboot and verify heartbeat.

**Section sources**
- [README.md:84-103](file://README.md#L84-L103)
- [ota_webserver.cpp:705-737](file://src/ota_webserver.cpp#L705-L737)

### Configuration Backups
- Retrieve and store configuration via the web UI’s configuration APIs.
- Store copies of axis mapping and CAN output rules.

**Section sources**
- [ota_webserver.cpp:565-626](file://src/ota_webserver.cpp#L565-L626)

### Hardware Inspection Procedures
- Check for cracks, burns, or discoloration on PCBs.
- Inspect solder joints for cold or cracked solder.
- Verify I2C and CAN connections are secure.

[No sources needed since this section provides general guidance]

### Shutdown Procedures and Power Cycling
- To shut down safely:
  - Stop operations and power off the machine.
  - Disconnect CAN bus connectors only after confirming power is off.
- To power cycle:
  - Power off, wait 10 seconds, reconnect CAN, then power on.
  - Observe LED patterns and heartbeat to confirm recovery.

**Section sources**
- [ecu_motor_driver.cpp:304-316](file://src/ecu_motor_driver.cpp#L304-L316)
- [ecu_joystick.cpp:174-185](file://src/ecu_joystick.cpp#L174-L185)

### Electrical Isolation and Grounding
- Maintain a single-point ground in the machine to avoid ground loops.
- Ensure the ESP32 CAN transceiver is properly powered and referenced to the same ground as actuators.
- Use shielded CAN cables and ensure the shield is grounded at one end only.

[No sources needed since this section provides general guidance]

### ESD Protection Guidelines
- Wear an approved ESD strap and connect to a grounded point.
- Work on an ESD-safe mat.
- Minimize handling of sensitive components; avoid static-prone materials near electronics.

[No sources needed since this section provides general guidance]

### Environmental Factors, Dust Protection, and Long-Term Storage
- Dust protection:
  - Enclose units in IP-rated housings.
  - Use gaskets and seals around connectors.
- Vibration:
  - Secure cables and harnesses to prevent strain.
- Temperature extremes:
  - Avoid prolonged exposure to heat or cold; store in climate-controlled environments.
- Long-term storage:
  - Power off and store in anti-static packaging.
  - Periodically power on briefly to verify functionality.

[No sources needed since this section provides general guidance]

### Safety Checklists

- Installation Checklist
  - Verify correct ECU type and address flags.
  - Check CAN wiring and termination.
  - Confirm power supply and ground connections.
  - Test LED indicators and heartbeat via web UI.

- Operation Checklist
  - Confirm all ECUs are present in heartbeat list.
  - Validate joystick and solenoid behavior.
  - Monitor error counters and bus status.

- Decommissioning Checklist
  - Power down the system.
  - Disconnect CAN bus connectors.
  - Store units in anti-static packaging.

**Section sources**
- [ota_webserver.cpp:506-563](file://src/ota_webserver.cpp#L506-L563)

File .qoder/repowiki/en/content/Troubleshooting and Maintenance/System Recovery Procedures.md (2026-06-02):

# System Recovery Procedures

<cite>
**Referenced Files in This Document**
- [README.md](file://README.md)
- [platformio.ini](file://platformio.ini)
- [main.cpp](file://src/main.cpp)
- [ecu_motor_driver.cpp](file://src/ecu_motor_driver.cpp)
- [ecu_joystick.cpp](file://src/ecu_joystick.cpp)
- [ota_webserver.cpp](file://src/ota_webserver.cpp)
- [ForwarderCAN.h](file://lib/ForwarderCAN/ForwarderCAN.h)
- [ForwarderCAN.cpp](file://lib/ForwarderCAN/ForwarderCAN.cpp)
- [ForwarderConfig.h](file://lib/ForwarderConfig/ForwarderConfig.h)
- [ForwarderConfig.cpp](file://lib/ForwarderConfig/ForwarderConfig.cpp)
- [web_state.cpp](file://src/web_state.cpp)
</cite>

## Table of Contents
1. [Introduction](#introduction)
2. [Project Structure](#project-structure)
3. [Core Components](#core-components)
4. [Architecture Overview](#architecture-overview)
5. [Detailed Component Analysis](#detailed-component-analysis)
6. [Dependency Analysis](#dependency-analysis)
7. [Performance Considerations](#performance-considerations)
8. [Troubleshooting Guide](#troubleshooting-guide)
9. [Conclusion](#conclusion)
10. [Appendices](#appendices)

## Introduction
This document defines comprehensive system recovery procedures for ForwarderKE, covering recovery from system crashes, data corruption, configuration loss, hardware faults, failed firmware updates, CAN bus arbitration failures, address claiming conflicts, stuck solenoid states, timeout conditions, power loss, CAN bus off conditions, and web interface failures. It also documents backup and restore procedures for configuration data, firmware recovery using Over-The-Air (OTA) methods, and emergency reset procedures. Step-by-step workflows and escalation procedures are included to return systems to operational status.

## Project Structure
ForwarderKE consists of:
- A shared CAN/J1939 library implementing address arbitration and message framing
- A configuration manager storing persistent settings in NVS
- Two ECU variants: motor driver and joystick
- An optional OTA web server for firmware updates and configuration management

```mermaid
graph TB
subgraph "ECUs"
MD["Motor Driver ECU"]
JS1["Joystick ECU 1"]
JS2["Joystick ECU 2"]
end
subgraph "Shared Libraries"
CAN["ForwarderCAN<br/>J1939-like protocol"]
CFG["ForwarderConfig<br/>NVS-backed config"]
end
subgraph "Optional OTA"
OTA["OTA Web Server<br/>HTTP + mDNS"]
end
MD --> CAN
JS1 --> CAN
JS2 --> CAN
MD --> CFG
JS1 --> CFG
JS2 --> CFG
MD -.-> OTA
JS1 -.-> OTA
JS2 -.-> OTA
```

**Diagram sources**
- [platformio.ini:17-80](file://platformio.ini#L17-L80)
- [main.cpp:11-17](file://src/main.cpp#L11-L17)
- [ecu_motor_driver.cpp:45](file://src/ecu_motor_driver.cpp#L45)
- [ecu_joystick.cpp:41](file://src/ecu_joystick.cpp#L41)
- [ota_webserver.cpp:766-791](file://src/ota_webserver.cpp#L766-L791)
- [ForwarderCAN.h:66-120](file://lib/ForwarderCAN/ForwarderCAN.h#L66-L120)
- [ForwarderConfig.h:64-92](file://lib/ForwarderConfig/ForwarderConfig.h#L64-L92)

**Section sources**
- [README.md:112-126](file://README.md#L112-L126)
- [platformio.ini:1-80](file://platformio.ini#L1-L80)
- [main.cpp:11-17](file://src/main.cpp#L11-L17)

## Core Components
- Address arbitration and bus management: Implements J1939-like address claiming with conflict resolution and bus-off recovery
- Configuration persistence: Stores mapping and CAN output rules in NVS with defaults on missing keys
- ECU-specific logic: Motor driver controls solenoids via PCA9685; joystick reads analog inputs and broadcasts telemetry
- OTA web server: Provides AP mode, web UI, and firmware update endpoint for recovery and maintenance

Key recovery-relevant behaviors:
- Address claiming conflict resolution and fallback to alternate address
- Automatic bus-off recovery via TWAI
- Safety timeout to turn off solenoids after inactivity
- Forced address override persisted in NVS
- Web UI for identifying modules, setting addresses, and updating firmware

**Section sources**
- [ForwarderCAN.h:66-120](file://lib/ForwarderCAN/ForwarderCAN.h#L66-L120)
- [ForwarderCAN.cpp:54-142](file://lib/ForwarderCAN/ForwarderCAN.cpp#L54-L142)
- [ForwarderConfig.h:64-92](file://lib/ForwarderConfig/ForwarderConfig.h#L64-L92)
- [ForwarderConfig.cpp:61-74](file://lib/ForwarderConfig/ForwarderConfig.cpp#L61-L74)
- [ecu_motor_driver.cpp:32-35](file://src/ecu_motor_driver.cpp#L32-L35)
- [ecu_motor_driver.cpp:332-337](file://src/ecu_motor_driver.cpp#L332-L337)
- [ecu_joystick.cpp:132-142](file://src/ecu_joystick.cpp#L132-L142)
- [ota_webserver.cpp:766-791](file://src/ota_webserver.cpp#L766-L791)

## Architecture Overview
The system uses a deterministic address arbitration protocol and NVS-backed configuration. On boot, each ECU attempts to claim its preferred address. If a conflict occurs, arbitration resolves it deterministically. NVS stores persistent settings and an override address. The motor driver enforces safety timeouts and controls solenoids. The OTA web server enables remote recovery and configuration.

```mermaid
sequenceDiagram
participant Boot as "ECU Boot"
participant CAN as "ForwarderCAN"
participant Arb as "Arbitration FSM"
participant NVS as "ForwarderConfig(NVS)"
participant ECU as "ECU Logic"
Boot->>CAN : begin(tx, rx, bitrate)
CAN->>CAN : check bus state (TWAI)
CAN->>CAN : initiate recovery if bus-off
CAN->>Arb : tryClaimAddress()
Arb->>CAN : sendAddressClaimed()
Arb->>CAN : monitor for conflicting claims
alt Conflict Detected
Arb->>Arb : mark cannot_claim, retry or alternate
else No Conflict
Arb->>Arb : mark claimed
end
Boot->>NVS : begin()
NVS-->>Boot : load forced address / defaults
Boot->>ECU : initialize per-ECU logic
```

**Diagram sources**
- [ForwarderCAN.cpp:13-52](file://lib/ForwarderCAN/ForwarderCAN.cpp#L13-L52)
- [ForwarderCAN.cpp:54-119](file://lib/ForwarderCAN/ForwarderCAN.cpp#L54-L119)
- [ForwarderCAN.cpp:121-142](file://lib/ForwarderCAN/ForwarderCAN.cpp#L121-L142)
- [ForwarderConfig.cpp:56-74](file://lib/ForwarderConfig/ForwarderConfig.cpp#L56-L74)

## Detailed Component Analysis

### Address Arbitration and Conflict Resolution
- Preferred address is attempted; if another device claims it, arbitration compares NAME fields and resolves deterministically
- On conflict, the module retries up to a limit or switches to an alternate derived from the NAME field
- Bus-off state triggers automatic recovery via TWAI

```mermaid
flowchart TD
Start(["Start Address Claim"]) --> Attempt["Attempt Preferred Address"]
Attempt --> Wait["Wait for Conflict Response"]
Wait --> Conflict{"Conflict Detected?"}
Conflict --> |No| Claimed["Mark Address Claimed"]
Conflict --> |Yes| Compare["Compare NAME with Peer"]
Compare --> Win{"We Win?"}
Win --> |Yes| Reclaim["Re-claim to Assert Dominance"]
Win --> |No| CannotClaim["Cannot Claim"]
CannotClaim --> RetryDelay["Wait Retry Interval"]
RetryDelay --> Attempts{"Attempts < Limit?"}
Attempts --> |Yes| Attempt
Attempts --> |No| Alternate["Derive Alternate Address from NAME"]
Alternate --> Attempt
Claimed --> End(["Ready"])
```

**Diagram sources**
- [ForwarderCAN.cpp:54-119](file://lib/ForwarderCAN/ForwarderCAN.cpp#L54-L119)
- [ForwarderCAN.cpp:121-142](file://lib/ForwarderCAN/ForwarderCAN.cpp#L121-L142)

**Section sources**
- [ForwarderCAN.h:74-83](file://lib/ForwarderCAN/ForwarderCAN.h#L74-L83)
- [ForwarderCAN.cpp:42-47](file://lib/ForwarderCAN/ForwarderCAN.cpp#L42-L47)
- [ForwarderCAN.cpp:82-89](file://lib/ForwarderCAN/ForwarderCAN.cpp#L82-L89)

### Safety Timeout and Solenoid Control
- The motor driver shuts off all solenoids if no CAN command is received within the safety timeout period
- This prevents stuck solenoid states during communication loss or CPU stalls

```mermaid
flowchart TD
Entry(["Loop Tick"]) --> Check["Has Solenoid Data Arrived Within Timeout?"]
Check --> |Yes| Apply["Apply PWM Values to PCA9685"]
Check --> |No| Timeout{"Timeout Elapsed Since Last Update?"}
Timeout --> |No| Wait["Continue Normal Operation"]
Timeout --> |Yes| AllOff["Turn Off All Solenoids (0 PWM)"]
Apply --> Wait
Wait --> Entry
```

**Diagram sources**
- [ecu_motor_driver.cpp:327-352](file://src/ecu_motor_driver.cpp#L327-L352)
- [ecu_motor_driver.cpp:332-337](file://src/ecu_motor_driver.cpp#L332-L337)

**Section sources**
- [ecu_motor_driver.cpp:32-35](file://src/ecu_motor_driver.cpp#L32-L35)
- [ecu_motor_driver.cpp:332-337](file://src/ecu_motor_driver.cpp#L332-L337)

### Configuration Persistence and Defaults
- NVS-backed storage persists forced address, axis mapping, and CAN output rules
- On missing keys, defaults are loaded to ensure safe operation
- Factory defaults are available for full reset

```mermaid
flowchart TD
LoadCfg["Load Motor Config from NVS"] --> HasKey{"Key Present?"}
HasKey --> |Yes| Unpack["Unpack Stored Bytes"]
HasKey --> |No| Defaults["Load Factory Defaults"]
Defaults --> Persist["Persist Defaults Back to NVS"]
Unpack --> Done(["Config Ready"])
Persist --> Done
```

**Diagram sources**
- [ForwarderConfig.cpp:76-104](file://lib/ForwarderConfig/ForwarderConfig.cpp#L76-L104)
- [ForwarderConfig.cpp:171-183](file://lib/ForwarderConfig/ForwarderConfig.cpp#L171-L183)

**Section sources**
- [ForwarderConfig.h:64-92](file://lib/ForwarderConfig/ForwarderConfig.h#L64-L92)
- [ForwarderConfig.cpp:61-74](file://lib/ForwarderConfig/ForwarderConfig.cpp#L61-L74)
- [ForwarderConfig.cpp:171-183](file://lib/ForwarderConfig/ForwarderConfig.cpp#L171-L183)

### OTA Firmware Update and Web Interface
- OTA builds enable AP mode, mDNS, and a web UI for firmware uploads and configuration
- Firmware updates are applied via HTTP POST to the update endpoint and trigger a restart

```mermaid
sequenceDiagram
participant Host as "Host Browser"
participant AP as "ESP32 AP"
participant OTA as "OTA Handler"
participant FS as "Filesystem"
participant MCU as "MCU Reset"
Host->>AP : POST /update (binary .bin)
AP->>OTA : handleUpdate()
OTA->>FS : Write chunk
OTA->>OTA : Finalize update
OTA-->>Host : 200 OK
OTA->>MCU : ESP.restart()
```

**Diagram sources**
- [ota_webserver.cpp:705-737](file://src/ota_webserver.cpp#L705-L737)
- [ota_webserver.cpp:766-791](file://src/ota_webserver.cpp#L766-L791)

**Section sources**
- [README.md:84-103](file://README.md#L84-L103)
- [platformio.ini:63-79](file://platformio.ini#L63-L79)
- [ota_webserver.cpp:766-791](file://src/ota_webserver.cpp#L766-L791)

## Dependency Analysis
- ECU selection is compile-time via build flags; runtime behavior branches accordingly
- Both ECUs depend on ForwarderCAN for bus arbitration and messaging
- Both ECUs depend on ForwarderConfig for persistent settings
- OTA web server depends on ForwarderCAN for module discovery and address changes

```mermaid
graph LR
Flags["Build Flags<br/>ECU_TYPE_*"] --> Main["main.cpp"]
Main --> MD["ecu_motor_driver.cpp"]
Main --> JS["ecu_joystick.cpp"]
MD --> CAN["ForwarderCAN"]
JS --> CAN
MD --> CFG["ForwarderConfig"]
JS --> CFG
MD -.-> OTA["ota_webserver.cpp"]
JS -.-> OTA
```

**Diagram sources**
- [platformio.ini:17-80](file://platformio.ini#L17-L80)
- [main.cpp:11-17](file://src/main.cpp#L11-L17)
- [ecu_motor_driver.cpp:45](file://src/ecu_motor_driver.cpp#L45)
- [ecu_joystick.cpp:41](file://src/ecu_joystick.cpp#L41)
- [ota_webserver.cpp:766-791](file://src/ota_webserver.cpp#L766-L791)

**Section sources**
- [platformio.ini:12-15](file://platformio.ini#L12-L15)
- [main.cpp:11-17](file://src/main.cpp#L11-L17)

## Performance Considerations
- TWAI bus-off recovery is automatic; frequent bus-off events indicate wiring or termination issues
- Address arbitration retries are bounded; repeated conflicts suggest incorrect preferred addresses or duplicate builds
- Safety timeout ensures solenoids are not stuck; tune timeout to balance responsiveness and safety

[No sources needed since this section provides general guidance]

## Troubleshooting Guide

### Recovery from System Crashes
- If the device becomes unresponsive, power cycle the unit. The motor driver will reinitialize PCA9685 and CAN, and the joystick will reinitialize inputs and CAN.
- If the device fails to claim an address, it will retry up to a limit or derive an alternate address; observe logs for claim attempts.

**Section sources**
- [ecu_motor_driver.cpp:290-325](file://src/ecu_motor_driver.cpp#L290-L325)
- [ecu_joystick.cpp:159-192](file://src/ecu_joystick.cpp#L159-L192)
- [ForwarderCAN.cpp:54-119](file://lib/ForwarderCAN/ForwarderCAN.cpp#L54-L119)

### Recovery from Data Corruption
- NVS corruption can cause missing keys; the configuration loader falls back to factory defaults. After restoring defaults, reconfigure mappings and CAN output rules via the web UI.
- To force a clean slate, clear the stored configuration namespace and reboot.

**Section sources**
- [ForwarderConfig.cpp:76-104](file://lib/ForwarderConfig/ForwarderConfig.cpp#L76-L104)
- [ForwarderConfig.cpp:171-183](file://lib/ForwarderConfig/ForwarderConfig.cpp#L171-L183)
- [web_state.cpp:6-19](file://src/web_state.cpp#L6-L19)

### Recovery from Configuration Loss
- If configuration is lost, reapply settings through the web UI:
  - Axis mapping: Configure source address, pots, channels, deadbands, and PWM ranges
  - CAN output rules: Define PF/SA filters and GPIO actions
- Save mappings and rules to persist them in NVS.

**Section sources**
- [ota_webserver.cpp:565-626](file://src/ota_webserver.cpp#L565-L626)
- [ota_webserver.cpp:659-703](file://src/ota_webserver.cpp#L659-L703)
- [ForwarderConfig.cpp:106-127](file://lib/ForwarderConfig/ForwarderConfig.cpp#L106-L127)
- [ForwarderConfig.cpp:159-169](file://lib/ForwarderConfig/ForwarderConfig.cpp#L159-L169)

### Recovery from Hardware Faults
- If PCA9685 is not detected, the motor driver initializes with a single PCA and adjusts channel counts accordingly. Replace or reseat the PCA to restore full channels.
- If CAN transceiver is not responding, verify wiring and supply; the driver checks bus state and initiates recovery automatically.

**Section sources**
- [ecu_motor_driver.cpp:85-99](file://src/ecu_motor_driver.cpp#L85-L99)
- [ForwarderCAN.cpp:42-47](file://lib/ForwarderCAN/ForwarderCAN.cpp#L42-L47)
- [ForwarderCAN.cpp:82-89](file://lib/ForwarderCAN/ForwarderCAN.cpp#L82-L89)

### Rollback Procedures for Failed Firmware Updates
- If OTA fails, the device remains in the previous working firmware. Use the OTA web UI to retry the update with a verified binary.
- If the device does not restart after a successful upload, power cycle to force a restart and re-apply the update.

**Section sources**
- [ota_webserver.cpp:705-737](file://src/ota_webserver.cpp#L705-L737)
- [README.md:84-103](file://README.md#L84-L103)

### Recovery from CAN Bus Arbitration Failures
- If address claiming fails repeatedly, verify preferred addresses in build flags and ensure only one device uses each address.
- If arbitration fails due to NAME mismatch, rebuild with correct ECU type and preferred address.

**Section sources**
- [platformio.ini:17-62](file://platformio.ini#L17-L62)
- [ForwarderCAN.cpp:121-142](file://lib/ForwarderCAN/ForwarderCAN.cpp#L121-L142)

### Restoration of Default Configurations
- Use the web UI to request configuration reset or clear NVS keys and reboot to reload factory defaults.
- After reset, reconfigure mappings and CAN output rules.

**Section sources**
- [ForwarderConfig.cpp:171-183](file://lib/ForwarderConfig/ForwarderConfig.cpp#L171-L183)
- [ota_webserver.cpp:565-626](file://src/ota_webserver.cpp#L565-L626)

### Recovering from Address Claiming Conflicts
- If a conflict occurs, the system retries up to a limit or switches to an alternate address derived from the NAME field.
- Manually override the address via the web UI to resolve persistent conflicts.

**Section sources**
- [ForwarderCAN.cpp:98-109](file://lib/ForwarderCAN/ForwarderCAN.cpp#L98-L109)
- [ForwarderCAN.cpp:104-107](file://lib/ForwarderCAN/ForwarderCAN.cpp#L104-L107)
- [ecu_motor_driver.cpp:234-244](file://src/ecu_motor_driver.cpp#L234-L244)
- [ecu_joystick.cpp:132-142](file://src/ecu_joystick.cpp#L132-L142)

### Resolving Stuck Solenoid States
- If solenoids remain on unexpectedly, verify CAN commands are arriving and the safety timeout is not exceeded.
- If timeout occurs, the motor driver will turn off all solenoids; restore communication to resume normal operation.

**Section sources**
- [ecu_motor_driver.cpp:332-337](file://src/ecu_motor_driver.cpp#L332-L337)

### Restoring Normal Operation After Timeout Conditions
- Ensure CAN bus is healthy and messages are being transmitted.
- Confirm heartbeat messages are received; the motor driver sends periodic status.

**Section sources**
- [ecu_motor_driver.cpp:277-288](file://src/ecu_motor_driver.cpp#L277-L288)
- [ecu_joystick.cpp:146-157](file://src/ecu_joystick.cpp#L146-L157)

### Backup and Restore Procedures for Configuration Data
- Backup: Use the web UI to export current configuration (axis mapping and CAN output rules).
- Restore: Re-import configuration or re-enter settings; confirm persistence in NVS.

**Section sources**
- [ota_webserver.cpp:565-626](file://src/ota_webserver.cpp#L565-L626)
- [ota_webserver.cpp:659-703](file://src/ota_webserver.cpp#L659-L703)

### Firmware Recovery Using OTA Methods
- Build an OTA-enabled environment and flash the device.
- Connect to the AP, open the web UI, and upload a verified firmware binary.
- Observe progress and allow the device to restart automatically.

**Section sources**
- [README.md:84-103](file://README.md#L84-L103)
- [platformio.ini:63-79](file://platformio.ini#L63-L79)
- [ota_webserver.cpp:705-737](file://src/ota_webserver.cpp#L705-L737)

### Emergency System Reset Procedures
- Power cycle the device to reset CAN and peripherals.
- Clear forced address in NVS to revert to preferred address.
- If the device fails to claim an address, rebuild with corrected flags and flash again.

**Section sources**
- [ecu_motor_driver.cpp:290-325](file://src/ecu_motor_driver.cpp#L290-L325)
- [ecu_joystick.cpp:159-192](file://src/ecu_joystick.cpp#L159-L192)
- [ForwarderConfig.cpp:71-74](file://lib/ForwarderConfig/ForwarderConfig.cpp#L71-L74)
- [platformio.ini:17-62](file://platformio.ini#L17-L62)

### Escalation Procedures for Unrecoverable Faults
- If repeated arbitration failures persist, replace the device or reflash with a unique preferred address.
- If OTA updates fail consistently, use a known-good binary and inspect host-side network connectivity.
- If NVS corruption is suspected, erase NVS partition and reflash with a fresh configuration.

**Section sources**
- [ForwarderCAN.cpp:98-109](file://lib/ForwarderCAN/ForwarderCAN.cpp#L98-L109)
- [ota_webserver.cpp:705-737](file://src/ota_webserver.cpp#L705-L737)
- [web_state.cpp:6-19](file://src/web_state.cpp#L6-L19)

### Recovery from Power Loss Situations
- On power-up, the device reinitializes CAN and peripherals; address arbitration resumes automatically.
- If the device does not claim an address, verify wiring and preferred address configuration.

**Section sources**
- [ForwarderCAN.cpp:13-52](file://lib/ForwarderCAN/ForwarderCAN.cpp#L13-L52)
- [ecu_motor_driver.cpp:290-325](file://src/ecu_motor_driver.cpp#L290-L325)
- [ecu_joystick.cpp:159-192](file://src/ecu_joystick.cpp#L159-L192)

### Recovery from CAN Bus Off Conditions
- The driver detects bus-off and initiates recovery automatically; persistent bus-off indicates wiring or termination issues requiring physical inspection.

**Section sources**
- [ForwarderCAN.cpp:42-47](file://lib/ForwarderCAN/ForwarderCAN.cpp#L42-L47)
- [ForwarderCAN.cpp:82-89](file://lib/ForwarderCAN/ForwarderCAN.cpp#L82-L89)

### Recovery from Web Interface Failures
- If the web UI is unreachable, verify AP mode is active and mDNS registration succeeded.
- Use the serial console to diagnose initialization issues; reflash OTA-enabled firmware if necessary.

**Section sources**
- [ota_webserver.cpp:766-791](file://src/ota_webserver.cpp#L766-L791)
- [README.md:84-103](file://README.md#L84-L103)

## Conclusion
ForwarderKE provides robust recovery mechanisms through automatic address arbitration, bus-off recovery, safety timeouts, NVS-backed configuration, and OTA firmware updates. By following the procedures outlined here—covering crashes, configuration loss, hardware faults, arbitration conflicts, timeout conditions, power loss, and web interface failures—you can reliably restore systems to operational status and escalate unresolved issues effectively.

[No sources needed since this section summarizes without analyzing specific files]

## Appendices

### Step-by-Step Recovery Workflows

- Address Claiming Conflict
  1. Observe logs for claim attempts and alternates
  2. Adjust preferred address in build flags or via web UI
  3. Rebuild and flash the device
  4. Verify address is claimed and heartbeat is visible

- Stuck Solenoid States
  1. Confirm CAN commands are arriving
  2. Check for timeout conditions and restore communication
  3. Verify solenoid outputs return to zero after timeout

- OTA Firmware Update Failure
  1. Re-attempt upload with a verified binary
  2. Power cycle if the device does not restart automatically
  3. Inspect host-side network and firewall settings

- Configuration Loss
  1. Reconfigure axis mapping and CAN output rules via web UI
  2. Save settings to persist in NVS
  3. Validate operation and confirm persistence

- Power Loss
  1. Power cycle the device
  2. Verify CAN initialization and address arbitration
  3. Confirm heartbeat and module discovery

- CAN Bus Off
  1. Inspect wiring and termination
  2. Verify bus state recovers automatically
  3. Investigate intermittent faults causing repeated bus-off

**Section sources**
- [ForwarderCAN.cpp:54-119](file://lib/ForwarderCAN/ForwarderCAN.cpp#L54-L119)
- [ecu_motor_driver.cpp:332-337](file://src/ecu_motor_driver.cpp#L332-L337)
- [ota_webserver.cpp:705-737](file://src/ota_webserver.cpp#L705-L737)
- [ForwarderConfig.cpp:106-127](file://lib/ForwarderConfig/ForwarderConfig.cpp#L106-L127)
- [platformio.ini:17-62](file://platformio.ini#L17-L62)

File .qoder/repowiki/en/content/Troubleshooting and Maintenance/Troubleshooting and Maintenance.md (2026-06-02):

# Troubleshooting and Maintenance

<cite>
**Referenced Files in This Document**
- [README.md](file://README.md)
- [platformio.ini](file://platformio.ini)
- [src/main.cpp](file://src/main.cpp)
- [src/ecu_motor_driver.cpp](file://src/ecu_motor_driver.cpp)
- [src/ecu_joystick.cpp](file://src/ecu_joystick.cpp)
- [src/ota_webserver.cpp](file://src/ota_webserver.cpp)
- [src/web_state.cpp](file://src/web_state.cpp)
- [src/can_output.h](file://src/can_output.h)
- [src/web_state.h](file://src/web_state.h)
</cite>

## Table of Contents
1. [Introduction](#introduction)
2. [Project Structure](#project-structure)
3. [Core Components](#core-components)
4. [Architecture Overview](#architecture-overview)
5. [Detailed Component Analysis](#detailed-component-analysis)
6. [Dependency Analysis](#dependency-analysis)
7. [Performance Considerations](#performance-considerations)
8. [Troubleshooting Guide](#troubleshooting-guide)
9. [Maintenance Procedures](#maintenance-procedures)
10. [Safety Guidelines](#safety-guidelines)
11. [Conclusion](#conclusion)
12. [Appendices](#appendices)

## Introduction
This document provides comprehensive troubleshooting and maintenance guidance for ForwarderKE, an ESP32-S3-based CAN bus control system for a forwarder’s hydraulic valve block. It focuses on diagnosing and resolving common issues such as CAN bus communication failures, address claiming conflicts, solenoid control problems, and web interface connectivity issues. It also documents built-in diagnostics (heartbeat monitoring, error counters, status reporting), maintenance procedures (OTA updates, configuration backups, preventive schedules), performance tuning, and recovery procedures for system failures.

## Project Structure
ForwarderKE is organized around a small set of source files implementing either a motor driver ECU or a joystick ECU, with optional OTA web server support. Build environments define compile-time flags that select the ECU type, preferred address, and hardware pin mappings.

```mermaid
graph TB
A["src/main.cpp"] --> B["src/ecu_motor_driver.cpp"]
A --> C["src/ecu_joystick.cpp"]
B --> D["src/ota_webserver.cpp"]
C --> D
B --> E["src/web_state.cpp"]
C --> E
B --> F["src/can_output.h"]
C --> G["src/web_state.h"]
H["platformio.ini"] --> B
H --> C
H --> D
I["README.md"] --> B
I --> C
I --> D
```

**Diagram sources**
- [src/main.cpp:1-32](file://src/main.cpp#L1-L32)
- [src/ecu_motor_driver.cpp:1-355](file://src/ecu_motor_driver.cpp#L1-L355)
- [src/ecu_joystick.cpp:1-239](file://src/ecu_joystick.cpp#L1-L239)
- [src/ota_webserver.cpp:1-809](file://src/ota_webserver.cpp#L1-L809)
- [src/web_state.cpp:1-20](file://src/web_state.cpp#L1-L20)
- [src/can_output.h:1-11](file://src/can_output.h#L1-L11)
- [src/web_state.h:1-23](file://src/web_state.h#L1-L23)
- [platformio.ini:1-80](file://platformio.ini#L1-L80)
- [README.md:1-131](file://README.md#L1-L131)

**Section sources**
- [README.md:112-126](file://README.md#L112-L126)
- [platformio.ini:1-80](file://platformio.ini#L1-L80)

## Core Components
- ECU selection and entry point:
  - The application entry point conditionally includes either the motor driver or joystick ECU implementation based on build flags.
- Motor Driver ECU:
  - Controls up to 16 solenoids via PCA9685 PWM drivers, reads joystick inputs, manages LEDs, broadcasts heartbeat/status, and supports OTA web UI.
- Joystick ECU:
  - Reads three potentiometers and two buttons, publishes joystick data, manages LED, and supports OTA web UI.
- OTA Web Server:
  - Provides a browser-based dashboard for diagnostics, module discovery, axis mapping, CAN output rules, and firmware updates.
- Shared state and CAN output:
  - Exposes runtime state for the web UI and defines CAN output rule structures for GPIO reactions.

Key runtime behaviors:
- Heartbeat/status broadcast every 1 second.
- Solenoid timeout: shuts off outputs after a period without CAN commands.
- Address claiming and conflict resolution via J1939-style startup arbitration.
- Automatic CAN bus recovery on errors.

**Section sources**
- [src/main.cpp:11-17](file://src/main.cpp#L11-L17)
- [src/ecu_motor_driver.cpp:290-325](file://src/ecu_motor_driver.cpp#L290-L325)
- [src/ecu_joystick.cpp:159-192](file://src/ecu_joystick.cpp#L159-L192)
- [src/ota_webserver.cpp:766-791](file://src/ota_webserver.cpp#L766-L791)
- [README.md:105-111](file://README.md#L105-L111)

## Architecture Overview
The system comprises three ECUs on a single 250 kbps CAN bus using J1939-like extended IDs. The motor driver ECU controls solenoids; joystick ECUs publish analog and button data. The OTA web server runs on-device to provide diagnostics and configuration.

```mermaid
graph TB
subgraph "CAN Bus (250 kbps)"
MD["Motor Driver ECU<br/>Address 0x20"]
J1["Joystick ECU 1<br/>Address 0x21"]
J2["Joystick ECU 2<br/>Address 0x22"]
end
subgraph "On-Device Web UI"
WS["OTA Web Server"]
end
J1 --> |"Joystick data"| MD
J2 --> |"Joystick data"| MD
MD --> |"Heartbeat/status"| WS
J1 --> |"Heartbeat/status"| WS
J2 --> |"Heartbeat/status"| WS
WS --> |"Configure mapping/routing"| MD
WS --> |"Firmware update"| MD
WS --> |"Firmware update"| J1
WS --> |"Firmware update"| J2
```

**Diagram sources**
- [README.md:8-41](file://README.md#L8-L41)
- [src/ota_webserver.cpp:506-563](file://src/ota_webserver.cpp#L506-L563)
- [src/ecu_motor_driver.cpp:277-288](file://src/ecu_motor_driver.cpp#L277-L288)
- [src/ecu_joystick.cpp:146-157](file://src/ecu_joystick.cpp#L146-L157)

## Detailed Component Analysis

### Motor Driver ECU Diagnostics and Control
- Solenoid control:
  - Uses PCA9685 PWM drivers to set solenoid duty cycles from joystick inputs or direct CAN commands.
  - Implements a safety timeout to turn off outputs if no commands are received within a configured interval.
- LED status:
  - Onboard LED indicates bus status, fast blinking during activity, and special modes for identification and offline conditions.
- Address claiming and configuration:
  - Supports setting a forced address via CAN and saving it to persistent storage.
  - Supports requesting and applying axis mapping configurations from the web UI.
- Heartbeat/status:
  - Broadcasts online/offline state, uptime, TX/RX counts, and device-specific info.

```mermaid
sequenceDiagram
participant CAN as "CAN Bus"
participant MD as "Motor Driver ECU"
participant PCA as "PCA9685 PWM"
participant LED as "Onboard LED"
CAN->>MD : "Joystick Pot/Buttons or Solenoid Command"
MD->>MD : "Decode PF/PS/SA"
alt "Joystick data"
MD->>MD : "Update g_joyPots[] and timestamps"
MD->>MD : "Map axes and compute PWM"
MD->>PCA : "Set PWM channels"
MD->>LED : "Blink fast"
else "Solenoid Command"
MD->>MD : "Scale 0-255 to 12-bit scale"
MD->>PCA : "Set PWM channels"
MD->>LED : "Blink fast"
end
MD->>CAN : "Broadcast Heartbeat/Status"
```

**Diagram sources**
- [src/ecu_motor_driver.cpp:184-275](file://src/ecu_motor_driver.cpp#L184-L275)
- [src/ecu_motor_driver.cpp:137-151](file://src/ecu_motor_driver.cpp#L137-L151)
- [src/ecu_motor_driver.cpp:277-288](file://src/ecu_motor_driver.cpp#L277-L288)

**Section sources**
- [src/ecu_motor_driver.cpp:69-83](file://src/ecu_motor_driver.cpp#L69-L83)
- [src/ecu_motor_driver.cpp:184-275](file://src/ecu_motor_driver.cpp#L184-L275)
- [src/ecu_motor_driver.cpp:277-288](file://src/ecu_motor_driver.cpp#L277-L288)
- [README.md:108-110](file://README.md#L108-L110)

### Joystick ECU Diagnostics and Inputs
- Input acquisition:
  - Reads two analog joysticks and two buttons with debounced logic.
- LED status:
  - Onboard LED reflects bus status and identification requests.
- Heartbeat/status:
  - Broadcasts online/offline state, uptime, and joystick identity.

```mermaid
sequenceDiagram
participant EXT as "External Joystick"
participant JS as "Joystick ECU"
participant LED as "Onboard LED"
participant CAN as "CAN Bus"
EXT->>JS : "Pot1/Pot2/Button inputs"
JS->>JS : "Read and debounce inputs"
alt "Changed or periodic"
JS->>CAN : "Send PF_JOYSTICK_* frames"
JS->>LED : "Update LED"
end
JS->>CAN : "Broadcast Heartbeat/Status"
```

**Diagram sources**
- [src/ecu_joystick.cpp:63-68](file://src/ecu_joystick.cpp#L63-L68)
- [src/ecu_joystick.cpp:194-236](file://src/ecu_joystick.cpp#L194-L236)
- [src/ecu_joystick.cpp:146-157](file://src/ecu_joystick.cpp#L146-L157)

**Section sources**
- [src/ecu_joystick.cpp:63-68](file://src/ecu_joystick.cpp#L63-L68)
- [src/ecu_joystick.cpp:194-236](file://src/ecu_joystick.cpp#L194-L236)

### OTA Web Server Diagnostics and Configuration
- Dashboard:
  - Shows real-time joystick pots/buttons, solenoid outputs, CAN stats, and discovered modules.
- Module discovery:
  - Tracks modules by parsing heartbeat frames and inferring type from payload fields.
- Remote configuration:
  - Allows sending identify/address-change commands and pushing axis/CAN-output rules to the motor driver.
- OTA update:
  - Provides a simple web UI to upload firmware binaries and reboots after successful update.

```mermaid
sequenceDiagram
participant Browser as "Browser"
participant WS as "OTA Web Server"
participant CAN as "CAN Bus"
participant MD as "Motor Driver ECU"
Browser->>WS : "GET /api/state"
WS-->>Browser : "JSON state (addresses, counts, modules)"
Browser->>WS : "POST /api/config (axes)"
WS->>CAN : "Send PF_CONFIG_AXIS to 0x20"
CAN-->>MD : "Frame delivered"
MD->>MD : "Load/save axis config"
Browser->>WS : "POST /update (.bin)"
WS->>WS : "Update.begin/write/end"
WS-->>Browser : "200 OK, then restart"
```

**Diagram sources**
- [src/ota_webserver.cpp:510-563](file://src/ota_webserver.cpp#L510-L563)
- [src/ota_webserver.cpp:587-626](file://src/ota_webserver.cpp#L587-L626)
- [src/ota_webserver.cpp:705-737](file://src/ota_webserver.cpp#L705-L737)
- [src/ecu_motor_driver.cpp:246-267](file://src/ecu_motor_driver.cpp#L246-L267)

**Section sources**
- [src/ota_webserver.cpp:506-563](file://src/ota_webserver.cpp#L506-L563)
- [src/ota_webserver.cpp:742-761](file://src/ota_webserver.cpp#L742-L761)
- [src/ota_webserver.cpp:766-791](file://src/ota_webserver.cpp#L766-L791)

## Dependency Analysis
- Build-time dependencies:
  - PlatformIO environments define MCU/board/framework, CAN bitrate, watchdog timeout, and per-ECU pin mappings and flags.
- Runtime dependencies:
  - ECU implementations depend on ForwarderCAN and ForwarderConfig libraries for CAN transport and persistent storage.
  - Motor driver depends on PCA9685 driver and NeoPixelBus for LEDs.
  - OTA web server depends on ESP32 WiFi/WebServer/Update and mDNS.

```mermaid
graph LR
PIO["platformio.ini"] --> ENV1["motor_driver env"]
PIO --> ENV2["joystick1 env"]
PIO --> ENV3["joystick2 env"]
PIO --> ENV4["*_ota env"]
ENV1 --> MD["ecu_motor_driver.cpp"]
ENV2 --> JS["ecu_joystick.cpp"]
ENV3 --> JS
ENV4 --> WS["ota_webserver.cpp"]
MD --> CANLIB["ForwarderCAN"]
JS --> CANLIB
MD --> CFG["ForwarderConfig"]
JS --> CFG
MD --> LED["NeoPixelBus"]
MD --> PWM["Adafruit_PWMServoDriver"]
WS --> WIFI["WiFi/WebServer/Update/mDNS"]
```

**Diagram sources**
- [platformio.ini:17-30](file://platformio.ini#L17-L30)
- [platformio.ini:31-46](file://platformio.ini#L31-L46)
- [platformio.ini:47-62](file://platformio.ini#L47-L62)
- [platformio.ini:63-80](file://platformio.ini#L63-L80)
- [src/ecu_motor_driver.cpp:5-12](file://src/ecu_motor_driver.cpp#L5-L12)
- [src/ecu_joystick.cpp:5-9](file://src/ecu_joystick.cpp#L5-L9)
- [src/ota_webserver.cpp:5-11](file://src/ota_webserver.cpp#L5-L11)

**Section sources**
- [platformio.ini:1-80](file://platformio.ini#L1-L80)
- [src/ecu_motor_driver.cpp:5-12](file://src/ecu_motor_driver.cpp#L5-L12)
- [src/ecu_joystick.cpp:5-9](file://src/ecu_joystick.cpp#L5-L9)
- [src/ota_webserver.cpp:5-11](file://src/ota_webserver.cpp#L5-L11)

## Performance Considerations
- CAN bus utilization:
  - Monitor TX/RX counts and error counters via the web dashboard to detect excessive traffic or bus errors.
- Solenoid responsiveness:
  - Adjust axis mapping deadbands and PWM ranges to minimize latency and improve control feel.
- Watchdog and timeouts:
  - Ensure watchdog timeout and solenoid safety timeout align with operational requirements to avoid unintended shutdowns.
- OTA bandwidth:
  - Prefer quiet periods for OTA updates to reduce risk of CAN interference.

[No sources needed since this section provides general guidance]

## Troubleshooting Guide

### Systematic Troubleshooting Workflows

#### Workflow 1: CAN Bus Communication Failure
- Initial checks:
  - Verify onboard LED patterns indicating bus offline or error conditions.
  - Confirm build flags and pin mappings match hardware.
- Diagnostic steps:
  - Use the web dashboard to confirm heartbeat frames from all ECUs and inspect TX/RX/error counters.
  - If heartbeat scanning shows no modules, check CAN wiring and termination.
- Recovery:
  - Re-flash firmware using OTA if the device remains reachable via AP.
  - Replace faulty transceiver or wiring if errors persist.

```mermaid
flowchart TD
Start(["Start"]) --> LED["Check onboard LED"]
LED --> Offline{"LED indicates offline?"}
Offline --> |Yes| Wiring["Inspect CAN wiring and termination"]
Offline --> |No| BusStats["Open web dashboard and check TX/RX/Error"]
Wiring --> BusStats
BusStats --> HB{"Heartbeats present?"}
HB --> |No| FixBus["Fix bus wiring/termination"]
HB --> |Yes| Next["Proceed to next steps"]
FixBus --> Reflash["OTA flash if reachable"]
Reflash --> End(["End"])
Next --> End
```

**Diagram sources**
- [src/ecu_motor_driver.cpp:153-182](file://src/ecu_motor_driver.cpp#L153-L182)
- [src/ecu_joystick.cpp:70-97](file://src/ecu_joystick.cpp#L70-L97)
- [src/ota_webserver.cpp:510-563](file://src/ota_webserver.cpp#L510-L563)

**Section sources**
- [src/ecu_motor_driver.cpp:153-182](file://src/ecu_motor_driver.cpp#L153-L182)
- [src/ecu_joystick.cpp:70-97](file://src/ecu_joystick.cpp#L70-L97)
- [src/ota_webserver.cpp:510-563](file://src/ota_webserver.cpp#L510-L563)

#### Workflow 2: Address Claiming Conflicts
- Symptoms:
  - Frequent reboots after address change or inconsistent behavior.
- Steps:
  - Use the web dashboard to send an identify command to suspected conflicting addresses.
  - Send a set-address command to force a new address and observe reboot.
  - Verify the new address appears in the dashboard and modules list.
- Prevention:
  - Use compile-time flags to pre-set preferred addresses and avoid collisions.

```mermaid
sequenceDiagram
participant User as "User"
participant WS as "OTA Web Server"
participant CAN as "CAN Bus"
participant ECU as "Target ECU"
User->>WS : "POST /api/identify {target}"
WS->>CAN : "Send PF_IDENTIFY to target"
CAN-->>ECU : "Identify frame"
ECU->>ECU : "Blink LED for 3s"
User->>WS : "POST /api/address {target,address}"
WS->>CAN : "Send PF_SET_ADDRESS"
CAN-->>ECU : "Address change frame"
ECU->>ECU : "Save and restart"
```

**Diagram sources**
- [src/ota_webserver.cpp:639-657](file://src/ota_webserver.cpp#L639-L657)
- [src/ecu_motor_driver.cpp:234-245](file://src/ecu_motor_driver.cpp#L234-L245)
- [src/ecu_joystick.cpp:132-142](file://src/ecu_joystick.cpp#L132-L142)

**Section sources**
- [src/ota_webserver.cpp:639-657](file://src/ota_webserver.cpp#L639-L657)
- [src/ecu_motor_driver.cpp:234-245](file://src/ecu_motor_driver.cpp#L234-L245)
- [src/ecu_joystick.cpp:132-142](file://src/ecu_joystick.cpp#L132-L142)

#### Workflow 3: Solenoid Control Problems
- Symptoms:
  - Solenoids do not respond to joystick inputs or commands.
- Steps:
  - Confirm joystick data is visible in the dashboard.
  - Check axis mapping configuration and deadband settings.
  - Verify PCA9685 presence and PWM updates.
  - If no recent commands, confirm safety timeout is not triggering.
- Recovery:
  - Recalculate axis mapping and save via web UI.
  - Power-cycle or reset the motor driver ECU if stuck.

```mermaid
flowchart TD
Start(["Start"]) --> Joy["Verify joystick data in dashboard"]
Joy --> Axes["Check axis mapping and deadbands"]
Axes --> PCA["Confirm PCA9685 presence and PWM"]
PCA --> Timeout{"Safety timeout triggered?"}
Timeout --> |Yes| Cmds["Ensure periodic commands are sent"]
Timeout --> |No| Next["Proceed to next steps"]
Cmds --> Next
Next --> End(["End"])
```

**Diagram sources**
- [src/ota_webserver.cpp:510-563](file://src/ota_webserver.cpp#L510-L563)
- [src/ecu_motor_driver.cpp:137-151](file://src/ecu_motor_driver.cpp#L137-L151)
- [src/ecu_motor_driver.cpp:332-337](file://src/ecu_motor_driver.cpp#L332-L337)

**Section sources**
- [src/ota_webserver.cpp:510-563](file://src/ota_webserver.cpp#L510-L563)
- [src/ecu_motor_driver.cpp:137-151](file://src/ecu_motor_driver.cpp#L137-L151)
- [src/ecu_motor_driver.cpp:332-337](file://src/ecu_motor_driver.cpp#L332-L337)

#### Workflow 4: Web Interface Connectivity Issues
- Symptoms:
  - Cannot reach the web UI or OTA page.
- Steps:
  - Confirm the device created an access point and connect to it.
  - Verify mDNS service and hostname resolution.
  - Check firewall and network settings.
- Recovery:
  - Reboot the device and retry connection.
  - Use the OTA update path to recover if the device is otherwise unreachable.

```mermaid
sequenceDiagram
participant Host as "Host PC"
participant AP as "Device AP"
participant DNS as "mDNS"
participant WS as "Web Server"
Host->>AP : "Connect to SSID 'forwarder-*'"
Host->>DNS : "Resolve hostname.local"
DNS-->>Host : "IP of device"
Host->>WS : "HTTP GET /"
WS-->>Host : "Dashboard HTML"
```

**Diagram sources**
- [src/ota_webserver.cpp:766-791](file://src/ota_webserver.cpp#L766-L791)

**Section sources**
- [src/ota_webserver.cpp:766-791](file://src/ota_webserver.cpp#L766-L791)

### Built-in Diagnostic Capabilities
- Heartbeat/Status:
  - All ECUs broadcast heartbeat frames containing online state, uptime, TX/RX counts, and device-specific fields.
- Error counters:
  - The web dashboard exposes error counts for the CAN interface.
- Module discovery:
  - The OTA web server scans heartbeat frames to discover and track modules.

**Section sources**
- [src/ecu_motor_driver.cpp:277-288](file://src/ecu_motor_driver.cpp#L277-L288)
- [src/ecu_joystick.cpp:146-157](file://src/ecu_joystick.cpp#L146-L157)
- [src/ota_webserver.cpp:510-563](file://src/ota_webserver.cpp#L510-L563)
- [src/ota_webserver.cpp:742-761](file://src/ota_webserver.cpp#L742-L761)

### Escalation Procedures for Complex Issues
- If OTA is unavailable:
  - Use a serial console to interpret debug output and confirm initialization stages.
- If address claiming fails repeatedly:
  - Force a new address via CAN and verify persistence.
- If solenoid control is intermittent:
  - Inspect power delivery to PCA9685 and wiring continuity.

**Section sources**
- [src/ecu_motor_driver.cpp:290-325](file://src/ecu_motor_driver.cpp#L290-L325)
- [src/ecu_joystick.cpp:159-192](file://src/ecu_joystick.cpp#L159-L192)

## Maintenance Procedures

### Firmware Update Cycles (OTA)
- Prepare:
  - Build the appropriate environment and produce a binary.
- Execute:
  - Connect to the device AP, navigate to the OTA page, and upload the binary.
  - The device reboots automatically upon success.
- Validate:
  - Confirm heartbeat and state in the dashboard after reboot.

**Section sources**
- [README.md:84-103](file://README.md#L84-L103)
- [src/ota_webserver.cpp:705-737](file://src/ota_webserver.cpp#L705-L737)

### Configuration Backups and Restores
- Axis mapping and CAN output rules are stored in persistent configuration and can be requested and applied via CAN or web UI.
- Backup strategy:
  - Periodically export configuration from the web UI and store separately.
  - Apply configuration remotely to avoid physical access.

**Section sources**
- [src/ecu_motor_driver.cpp:257-267](file://src/ecu_motor_driver.cpp#L257-L267)
- [src/ota_webserver.cpp:565-626](file://src/ota_webserver.cpp#L565-L626)

### Preventive Maintenance Schedules
- Monthly:
  - Inspect CAN wiring and terminations.
  - Verify LED status and heartbeat presence.
- Quarterly:
  - Review error counters and adjust mapping/deadband settings.
  - Validate OTA update procedure in controlled conditions.

[No sources needed since this section provides general guidance]

## Safety Guidelines
- CAN bus safety:
  - Address claiming prevents collisions; ensure only one ECU attempts to claim an address at a time.
  - Automatic bus-off recovery helps recover from errors.
- Electrical hazards:
  - Observe voltage limits for PCA9685 and solenoid loads.
  - Use appropriate fusing and wiring gauge for the installed solenoids.
- Equipment handling:
  - Power down devices before connecting/disconnecting wiring.
  - Use clean, dry hands and avoid working near wet surfaces.

**Section sources**
- [README.md:105-111](file://README.md#L105-L111)

## Performance Tuning and Monitoring Best Practices
- Optimize axis mapping:
  - Adjust deadbands to minimize noise and improve responsiveness.
  - Tune PWM ranges to match actuator characteristics.
- Monitor bus health:
  - Track TX/RX/error counters; rising errors indicate bus stress or wiring issues.
- Reduce contention:
  - Limit unnecessary broadcast frames and ensure periodic command rates meet safety timeouts.

[No sources needed since this section provides general guidance]

## Conclusion
ForwarderKE offers robust built-in diagnostics and a practical OTA web interface for field maintenance. By leveraging heartbeat/status reporting, error counters, and remote configuration, most issues can be diagnosed and resolved quickly. Adhering to the troubleshooting workflows, safety guidelines, and maintenance schedules will keep the system reliable in demanding field conditions.

[No sources needed since this section summarizes without analyzing specific files]

## Appendices

### Diagnostic Checklist
- CAN bus:
  - LED status, heartbeat presence, TX/RX/error counters.
- Addressing:
  - Identify and set address via web UI; verify reboot and new address.
- Solenoids:
  - Confirm joystick data, axis mapping, PCA9685 presence, and safety timeout behavior.
- Web UI:
  - Access AP, resolve hostname, and validate dashboard.

**Section sources**
- [src/ota_webserver.cpp:510-563](file://src/ota_webserver.cpp#L510-L563)
- [src/ota_webserver.cpp:639-657](file://src/ota_webserver.cpp#L639-L657)
- [src/ecu_motor_driver.cpp:277-288](file://src/ecu_motor_driver.cpp#L277-L288)

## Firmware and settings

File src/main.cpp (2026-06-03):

#include <Arduino.h>

// =============================================================================
// Forwarder CAN Controller - Main Application
// =============================================================================
// Build flags select the ECU type:
//   ECU_TYPE_MOTOR_DRIVER  -> Valve block controller with PCA9685
//   ECU_TYPE_JOYSTICK      -> Joystick controller with pots & buttons
// =============================================================================

#if defined(ECU_TYPE_MOTOR_DRIVER)
    #include "ecu_motor_driver.h"
#elif defined(ECU_TYPE_JOYSTICK)
    #include "ecu_joystick.h"
#else
    #error "No ECU_TYPE defined! Define ECU_TYPE_MOTOR_DRIVER or ECU_TYPE_JOYSTICK"
#endif

void setup() {
    Serial.begin(115200);
#if ARDUINO_USB_CDC_ON_BOOT
    // Wait for USB-CDC enumeration
    unsigned long startWait = millis();
    while (!Serial && millis() - startWait < 3000) { delay(10); }
#else
    delay(500);
#endif
    Serial.println("\n============================================");
    Serial.println("  Forwarder CAN Controller Starting...");
    Serial.println("============================================");

    ecu_setup();
}

void loop() {
    ecu_loop();
    yield();
}

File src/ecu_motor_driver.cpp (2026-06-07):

#include "ecu_motor_driver.h"

#if defined(ECU_TYPE_MOTOR_DRIVER)

#include <Wire.h>
#include <Adafruit_PWMServoDriver.h>
#include <NeoPixelBus.h>
#include "ForwarderCAN.h"
#include "ForwarderConfig.h"
#include "ota_webserver.h"
#include "web_state.h"
#include "can_output.h"

#ifndef CAN_TX_PIN
#define CAN_TX_PIN 5
#endif
#ifndef CAN_RX_PIN
#define CAN_RX_PIN 4
#endif
#ifndef PCA9685_SDA
#define PCA9685_SDA 21
#endif
#ifndef PCA9685_SCL
#define PCA9685_SCL 22
#endif
#ifndef PCA9685_I2C_ADDR1
#define PCA9685_I2C_ADDR1 0x40
#endif
#ifndef PCA9685_I2C_ADDR2
#define PCA9685_I2C_ADDR2 0x41
#endif
#ifndef SAFETY_TIMEOUT_MS
#define SAFETY_TIMEOUT_MS 500
#endif
#ifndef WS2812_PIN
#define WS2812_PIN 48
#endif

static Adafruit_PWMServoDriver pca1 = Adafruit_PWMServoDriver(PCA9685_I2C_ADDR1);
static Adafruit_PWMServoDriver pca2 = Adafruit_PWMServoDriver(PCA9685_I2C_ADDR2);
bool g_pca2Present = false;

static NeoPixelBus<NeoGrbFeature, Neo800KbpsMethod> strip(1, WS2812_PIN);
ForwarderCAN* g_can = nullptr;
ForwarderConfig cfgMgr("motorcfg");

MotorConfig g_motorCfg;
uint16_t g_solenoidValues[MAX_AXIS_COUNT] = {0};
static uint32_t lastSolenoidUpdate = 0;
static uint32_t lastHeartbeat = 0;
static bool g_outputDirty = false;
static uint32_t lastOutputBroadcast = 0;
static uint32_t lastLedUpdate = 0;

// Motor test mode - allows manual control of outputs via web UI
bool g_testMode = false;
uint16_t g_testValues[16] = {0};  // Manual test values for outputs 1-16
uint32_t g_lastTestCmd = 0;       // Auto-disable after 10s timeout

static uint8_t ledR = 0, ledG = 0, ledB = 20;
static bool blinkFast = false;
static uint32_t blinkTimer = 0;
static uint32_t identifyTimer = 0;
static bool identifyActive = false;

uint16_t g_joyPots[256][3] = {{0}};
uint8_t g_joyButtons[256] = {0};
uint32_t g_joyUpdateTime[256] = {0};
uint32_t g_joyButtonUpdateTime[256] = {0};
CanOutputRule g_canOutputRules[MAX_CAN_OUTPUT_RULES];

static const uint8_t ECU_NAME[8] = {
    0x00, 0x00, 0x00, 0x00,
    0x00, 0x00, 0x00,
    (ECU_NAME_MOTOR_DRIVER & 0xFF)
};

static void setPWM(uint8_t channel, uint16_t value) {
    if (value > 4095) value = 4095;
    if (channel < 16) {
        pca1.setPWM(channel, 0, value);
    } else if (channel < 32 && g_pca2Present) {
        pca2.setPWM(channel - 16, 0, value);
    }
}

// Track last written PWM values for change detection
static uint16_t lastPWM[32] = {0};
static uint32_t lastPWMDebug = 0;
static void setPWMTracked(uint8_t channel, uint16_t value) {
    if (channel < 32 && value != lastPWM[channel]) {
        lastPWM[channel] = value;
        g_outputDirty = true;
        if (millis() - lastPWMDebug >= 2000) {
            lastPWMDebug = millis();
            Serial.print("[PWM] ");
            for (int c = 0; c < 16; c++) {
                if (lastPWM[c] > 0) Serial.printf("ch%d=%d ", c, lastPWM[c]);
            }
            Serial.println();
        }
    }
    setPWM(channel, value);
}

static void allOff(const char* caller) {
    Serial.printf("[PWM] allOff() called from %s\n", caller);
    for (int i = 0; i < MAX_AXIS_COUNT; i++) {
        g_solenoidValues[i] = 0;
        setPWMTracked(i, 0);
    }
}

static void initPCA() {
    Wire.setPins(PCA9685_SDA, PCA9685_SCL);
    Wire.begin();
    pca1.begin();
    pca1.setOscillatorFrequency(25000000);
    pca1.setPWMFreq(200);
    Wire.beginTransmission(PCA9685_I2C_ADDR2);
    g_pca2Present = (Wire.endTransmission() == 0);
    if (g_pca2Present) {
        pca2.begin();
        pca2.setOscillatorFrequency(25000000);
        pca2.setPWMFreq(200);
        Serial.println("[MotorDriver] 2nd PCA9685 detected at 0x41");
    }
}

// Apply exponential curvature to a value 0-255
// curveExp: 2=linear(1.0), 3=1.5, 4=2.0, 5=2.5, 6=3.0
static uint32_t applyCurve(uint32_t t, uint8_t curveExp) {
    if (curveExp <= 2) return t;  // Linear
    float normalized = t / 255.0f;
    float exponent = curveExp / 2.0f;
    float curved = powf(normalized, exponent);
    return (uint32_t)(curved * 255.0f);
}

// Paired channel output: fwdCh and revCh get PWM values
// For bidirectional axes: outputChannel = forward, outputChannel+1 = reverse
// For unidirectional axes: only outputChannel is used
// Invert flag swaps forward <-> reverse directions
static void mapAxis(const AxisConfig& axis, uint16_t potValue, uint16_t& fwdCh, uint16_t& revCh) {
    fwdCh = 0;
    revCh = 0;
    if (!axis.isEnabled()) return;
    if (axis.isBidirectional()) {
        if (potValue < axis.deadbandMin) {
            // Reverse direction -> paired channel
            uint16_t range = axis.deadbandMin;
            if (range == 0) range = 1;
            uint32_t t = ((uint32_t)(axis.deadbandMin - potValue) * 255u) / range;
            if (t > 255) t = 255;
            t = applyCurve(t, axis.curveExp);  // Apply curvature
            uint8_t pwm = axis.pwmMin + (uint8_t)(((uint32_t)(axis.pwmMax - axis.pwmMin) * t) / 255u);
            revCh = ((uint16_t)pwm * 4095u) / 255u;
            fwdCh = 0;
        } else if (potValue > axis.deadbandMax) {
            // Forward direction -> base channel
            uint16_t range = 1023 - axis.deadbandMax;
            if (range == 0) range = 1;
            uint32_t t = ((uint32_t)(potValue - axis.deadbandMax) * 255u) / range;
            if (t > 255) t = 255;
            t = applyCurve(t, axis.curveExp);  // Apply curvature
            uint8_t pwm = axis.pwmMin + (uint8_t)(((uint32_t)(axis.pwmMax - axis.pwmMin) * t) / 255u);
            fwdCh = ((uint16_t)pwm * 4095u) / 255u;
            revCh = 0;
        }
        // In deadband: both stay 0
    } else {
        if (potValue > axis.deadbandMax) {
            uint16_t range = 1023 - axis.deadbandMax;
            if (range == 0) range = 1;
            uint32_t t = ((uint32_t)(potValue - axis.deadbandMax) * 255u) / range;
            if (t > 255) t = 255;
            t = applyCurve(t, axis.curveExp);  // Apply curvature
            uint8_t pwm = axis.pwmMin + (uint8_t)(((uint32_t)(axis.pwmMax - axis.pwmMin) * t) / 255u);
            fwdCh = ((uint16_t)pwm * 4095u) / 255u;
        }
    }
    // Invert: swap forward and reverse channels
    if (axis.isInverted()) {
        uint16_t tmp = fwdCh;
        fwdCh = revCh;
        revCh = tmp;
    }
}

static uint32_t lastAxisDebug = 0;

// Evaluate whether an axis's button gate condition is met
static bool isAxisGateActive(const AxisConfig& axis) {
    switch (axis.buttonGate) {
        case BUTTON_GATE_BTN1_PRESSED:
            return (g_joyButtons[axis.sourceAddress] & 0x01) != 0;
        case BUTTON_GATE_BTN1_RELEASED:
            return (g_joyButtons[axis.sourceAddress] & 0x01) == 0;
        case BUTTON_GATE_NONE:
        default:
            return true;  // No gating, always active
    }
}
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

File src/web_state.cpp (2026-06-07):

#include "web_state.h"

// Provide default definitions for globals that are only defined
// in the ECU file that is NOT being compiled in this build.

#if !defined(ECU_TYPE_MOTOR_DRIVER)
uint16_t g_joyPots[256][3] = {{0}};
uint8_t g_joyButtons[256] = {0};
uint32_t g_joyUpdateTime[256] = {0};
uint32_t g_joyButtonUpdateTime[256] = {0};
uint16_t g_solenoidValues[MAX_AXIS_COUNT] = {0};
MotorConfig g_motorCfg;
bool g_pca2Present = false;
CanOutputRule g_canOutputRules[MAX_CAN_OUTPUT_RULES];
#endif

#if !defined(ECU_TYPE_JOYSTICK)
uint16_t g_localPot1 = 512, g_localPot2 = 512, g_localPot3 = 512;
bool g_localBtn1 = false, g_localBtn2 = false;
uint8_t g_ecuJoystickId = 0;
#endif

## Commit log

2026-06-08 Add the joystick files
    [joystick.3mf, joystick.f3d]
2026-06-08 Update README with joystick wiring and images
